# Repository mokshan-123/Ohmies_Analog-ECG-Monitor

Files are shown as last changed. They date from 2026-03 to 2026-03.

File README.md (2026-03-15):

#  Heart ECG Monitor — Ohmies

A portable, battery-powered analog front-end for single-lead ECG signal acquisition, designed as part of the **EN2091 Laboratory Practice and Projects Module** at the University of Moratuwa, Faculty of Engineering, Department of Electronic and Telecommunication Engineering.

---

##  Team — Ohmies | Contributors

| Name | Index |
|---|---|
| Keerawella K.P.C.P. | 230332B |
| Jathunwaththa J.C.R.N. | 230266B |
| Induwara M.L.A.S. | 230261F |
| Colombage D.M. | 230108U |

---

##  Repository Structure

```
Ohmies_ECG/
├── PCB_Files/           # EasyEDA Pro PCB design files
├── Schematic_Files/     # Circuit schematics
├── Enclosure_Files/     # SolidWorks & STL files for the 3D printed enclosure
├── Docs/                # Images, photos, and project documents
│   ├── block_diagram.png
│   ├── sch.png
│   ├── bode_plot.png
│   ├── transient_response.png
│   ├── enclosure_front.jpg
│   ├── enclosure_open.jpg
│   ├── Final_Report.pdf
│   ├── Presentation.pdf
│   ├── User_Manual.pdf
│   └── Datasheet.pdf
├── LICENSE
└── README.md
```

---

##  Overview

This project implements a complete analog signal conditioning chain to capture, amplify, and filter biopotential ECG signals from the human body. ECG signals are extremely low amplitude (microvolts to millivolts) and are typically corrupted by power-line interference, baseline wander, and muscle artifacts. The device addresses all of these challenges in hardware.

The system was designed with emphasis on **patient safety**, **signal integrity**, and **noise rejection**, and successfully acquired live ECG waveforms with clearly identifiable P, QRS, and T complexes.

---

##  Documents

| Document | Link |
|---|---|
| Final Report | [Final_Report.pdf](./Docs/Final_Report.pdf) |
| Presentation | [Presentation.pdf](./Docs/Presentation.pdf) |
| User Manual | [User_Manual.pdf](./Docs/User_Manual.pdf) |
| Datasheet | [Datasheet.pdf](./Docs/Datasheet.pdf) |

---

##  System Architecture

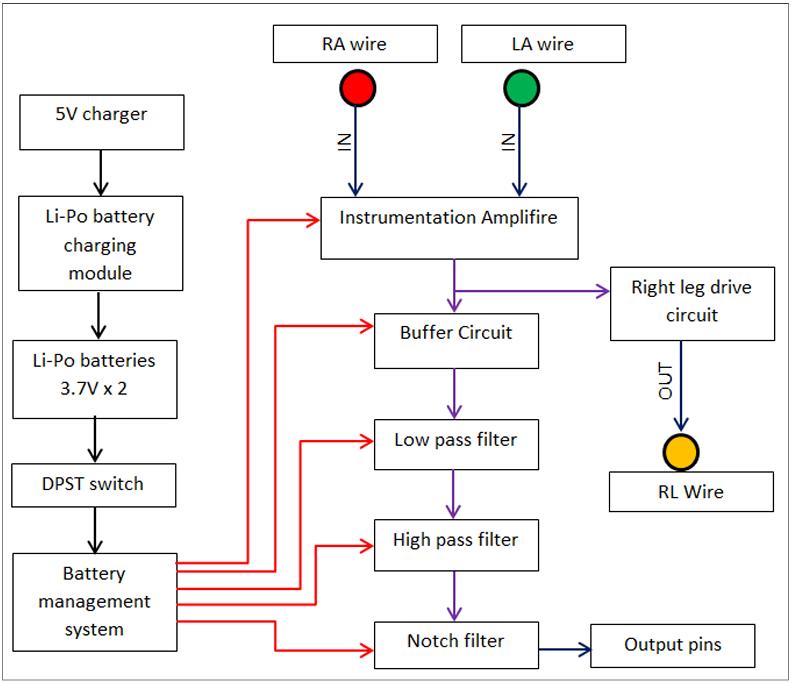
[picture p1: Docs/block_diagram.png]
Block Diagram


---

##  Circuit Stages

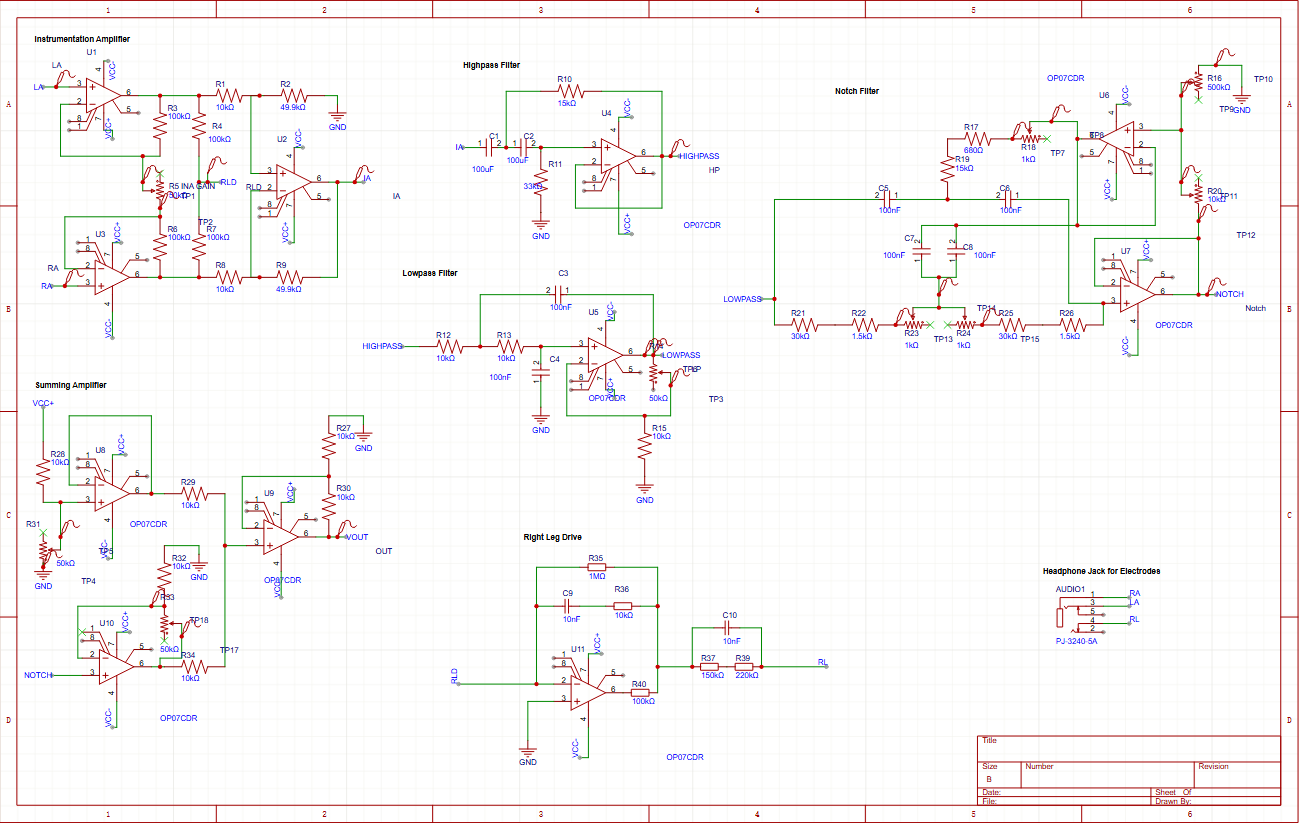
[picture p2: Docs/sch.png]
Schematic


### Instrumentation Amplifier
- Extracts the differential signal between the Left Arm (LA) and Right Arm (RA) electrodes
- High input impedance, high CMRR
- Adjustable gain via external resistor R5:

$$V_{IA} = \frac{R_2}{R_1}\left(1 + \frac{2R_3}{R_5}\right)(V_{LA} - V_{RA})$$

### Right Leg Drive (RLD)
- Actively cancels common-mode interference by sensing, inverting, and feeding it back to the body via the RL electrode
- Significantly improves effective CMRR and prevents static charge buildup

### High-Pass Filter
- Topology: 2nd-order Sallen–Key HPF
- Cutoff frequency: **~0.072 Hz**
- Components: R10 = 15 kΩ, R11 = 33 kΩ, C1 = C2 = 100 µF
- Removes DC offsets, baseline wander, and slow motion artifacts

### Low-Pass Filter
- Topology: 2nd-order adjustable-gain Sallen–Key LPF
- Cutoff frequency: **~159.2 Hz**
- Components: R12 = R13 = 10 kΩ, C3 = C4 = 100 nF
- Removes electromyographic interference and high-frequency EM noise

### Notch Filter
- Topology: Active twin-T notch filter with multiple feedback
- Notch frequency: **~50.37 Hz**
- Components: R = 31.6 kΩ, C = 100 nF
- Suppresses 50 Hz power-line interference

### Power Circuit
- Dual ±3.7 V supply from two series-connected Li-Po batteries
- Battery-powered for electrical isolation from mains and reduced 50 Hz susceptibility
- Includes a BMS (Battery Management System) and USB-C charging via a Li-Po charging module
- Controlled by a DPST switch

---

##  PCB Design

- **Tool:** EasyEDA Pro
- **Stackup:** 4-layer — Signal-1 / Power / GND / Signal-2
- Solid ground plane with ground fills on all layers, stitched via vias
- Wide power traces to minimise inductance and heating
- Analog signal paths kept short and isolated from power regulation circuitry

---

##  Enclosure

- **CAD Tool:** SolidWorks
- **Material:** PLA (3D printed)
- **Dimensions:** 110 mm × 80 mm × 60 mm
- **Features:**
  - Power switch
  - 3.5 mm audio jack for electrode input
  - USB-C charging port
  - Header pins for oscilloscope output
  - Ventilation openings
  - Internal compartment for batteries and BMS

>  SolidWorks and STL files are available in the [`Enclosure_Files/`](./Enclosure_Files) folder.

---

## 🔩 Final Prototype

| Front View | Internal Assembly |
|---|---|
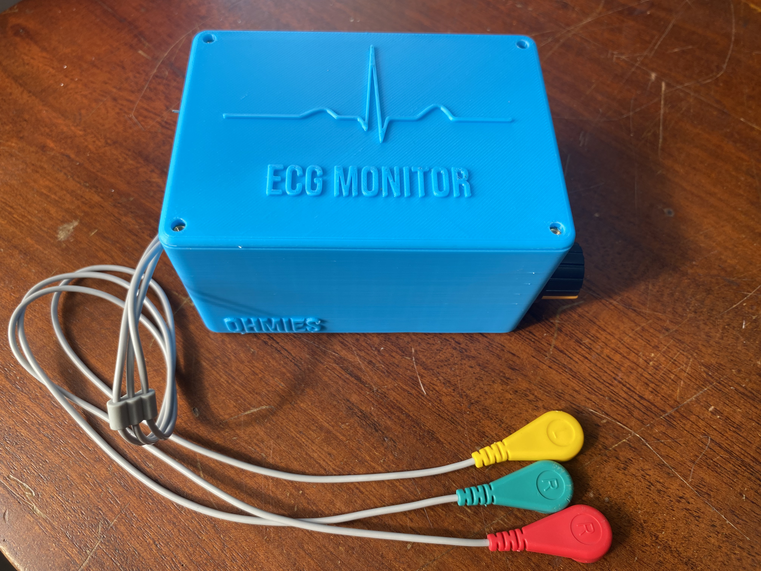
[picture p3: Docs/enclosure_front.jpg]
Enclosure Front
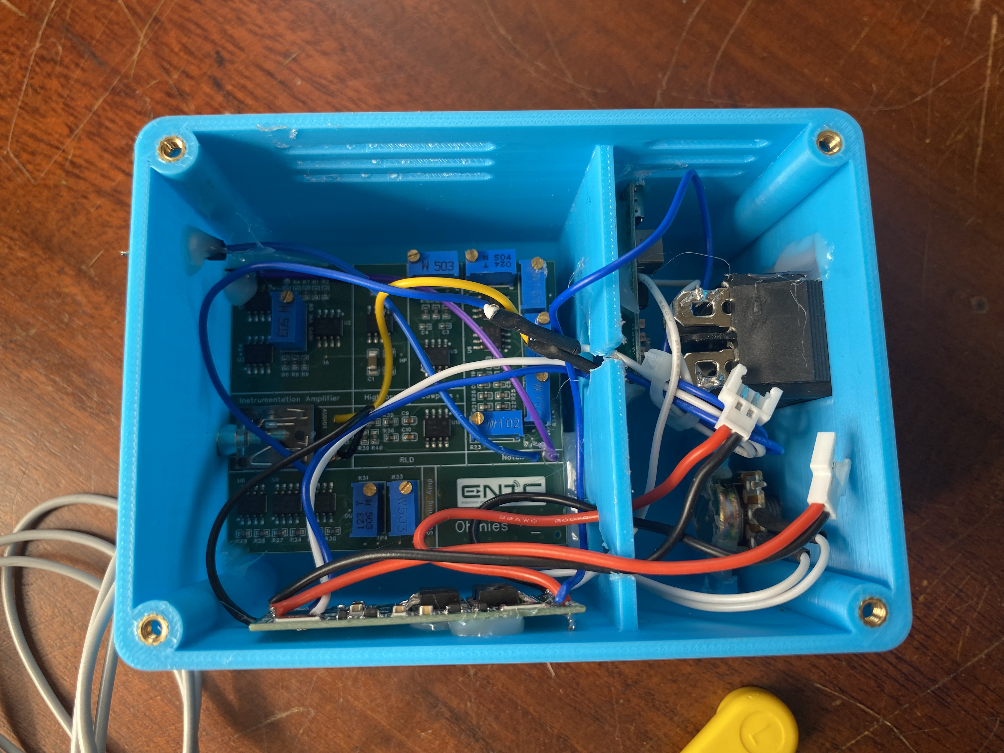
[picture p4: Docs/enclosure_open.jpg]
Enclosure Open
|  |  |

---

##  Testing & Results

### Simulation (LTSpice)
- Bode plot analysis confirmed correct passband and stopband behaviour across all filter stages
- Transient analysis verified effective 50 Hz attenuation while preserving ECG morphology

**Bode Plot — Combined filter frequency response:**

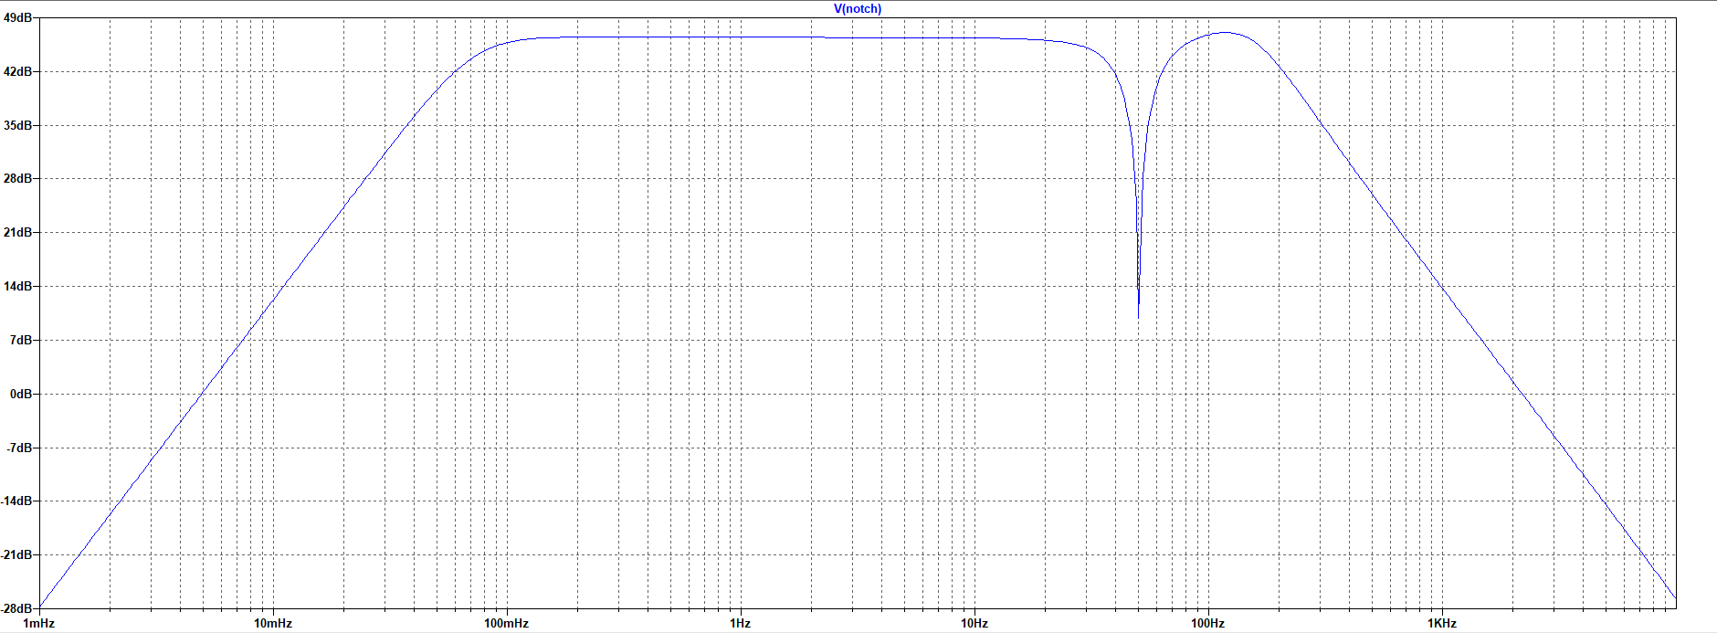
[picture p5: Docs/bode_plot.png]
Bode Plot


**Transient Response — Input (blue) vs. notch filter output (green):**

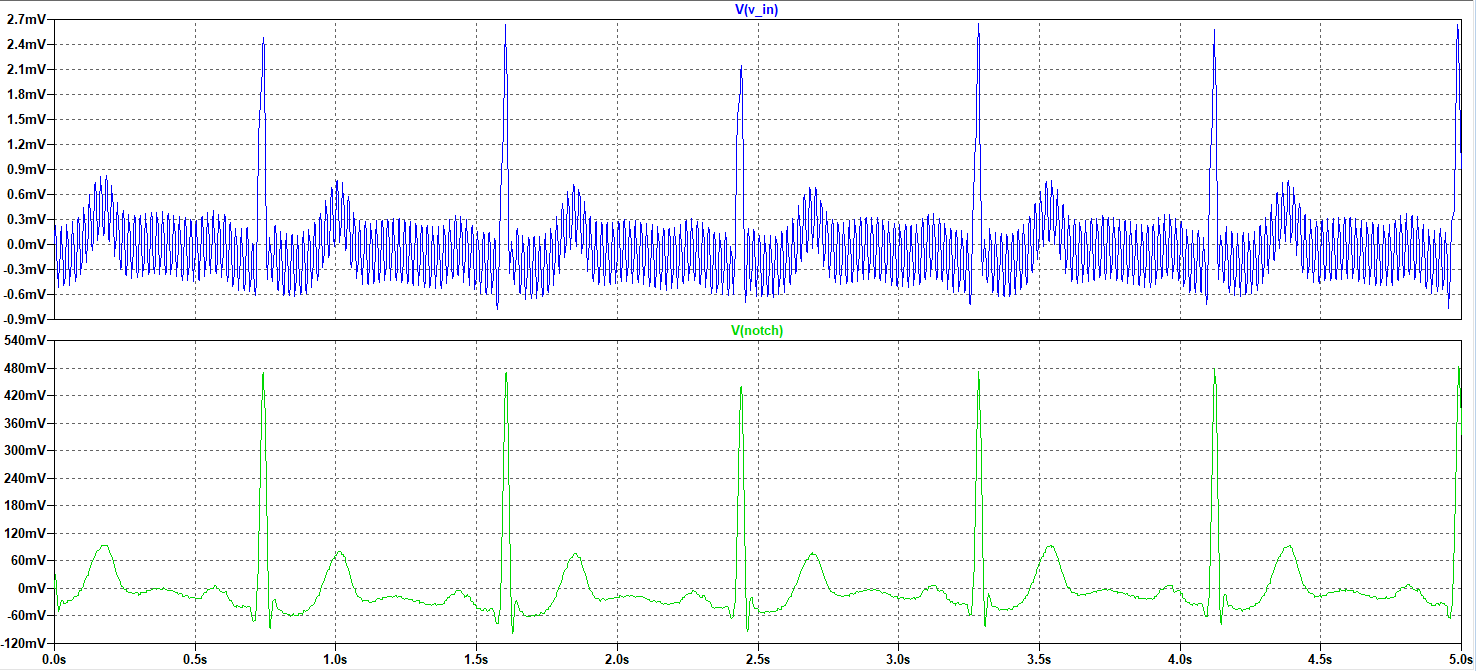
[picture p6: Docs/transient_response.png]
Transient Response


### Hardware Testing
1. **Breadboard prototype** — iterative tuning of gain and cutoff frequencies, cross-verified in LTSpice
2. **PCB prototype** — continuity checks, functional tests; results consistent with simulation
3. **Live subject test** — clearly identifiable P, QRS, and T complexes acquired via surface electrodes

---

##  Bill of Materials (Key Components)

| Component | Quantity |
|---|---|
| OP07 Op-Amp | 11 |
| 10 kΩ Resistor | 12 |
| 100 nF Capacitor | 6 |
| 100 µF Capacitor | 2 |
| 49.9 kΩ Resistor | 2 |
| 100 kΩ Resistor | 5 |
| 50 kΩ Trimmer | 4 |
| 1 kΩ Trimmer | 3 |
| Li-Po Battery (3.7 V) | 2 |
| Battery Management System | 1 |
| ECG wire set (3.5 mm jack) | 1 |

> See the full BOM in the [Final Report](./Docs/Final_Report.pdf).

---

##  Future Improvements

- Onboard OLED/TFT display for real-time waveform visualisation
- ESP32 integration for Wi-Fi/Bluetooth wireless monitoring
- Cloud-based ECG storage and remote access
- Real-time R-peak detection and BPM calculation
- Digital FIR/IIR filters to supplement or replace analog stages
- Adaptive filtering for motion artifact suppression
- SD card data logging and playback
- Multi-lead ECG expansion
- Low-power optimisation for extended battery life
- Enhanced isolation and medical device safety compliance

---

##  References

1. Webster, J. G. (2009). *Medical Instrumentation: Application and Design.* John Wiley & Sons.
2. Winter, B. B., & Webster, J. G. (1983). Driven-right-leg circuit design. *IEEE Transactions on Biomedical Engineering*, (1), 62–66.
3. Texas Instruments. (2019). *A Basic Guide to Thermocouple Measurements* (Application Note).

---

*University of Moratuwa — Faculty of Engineering — Department of Electronic and Telecommunication Engineering*

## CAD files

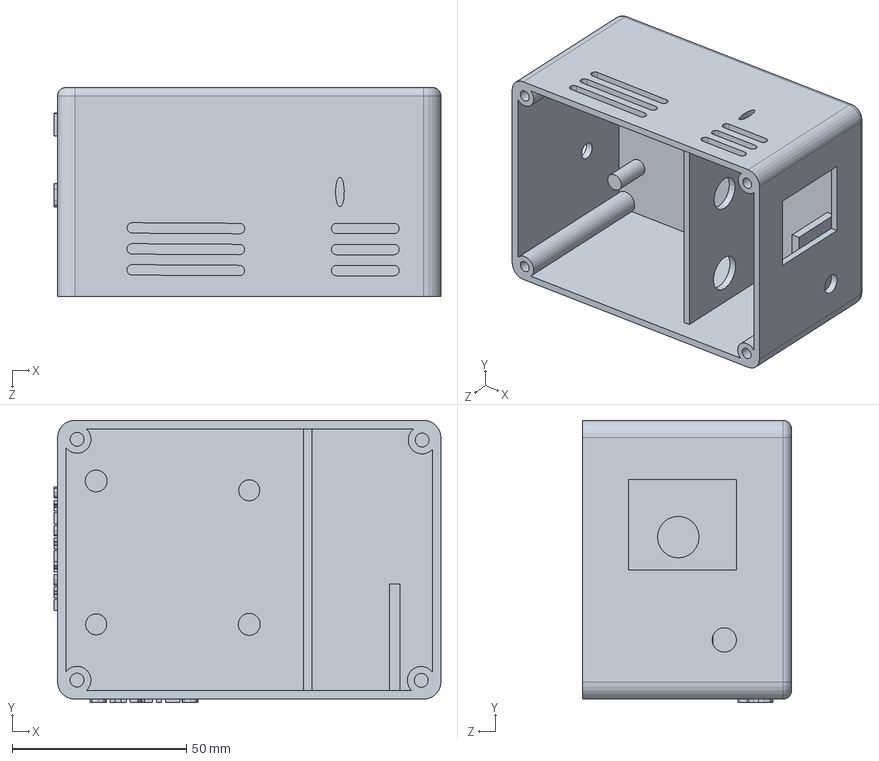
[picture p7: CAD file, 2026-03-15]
Enclosure_Files/Box.SLDPRT
111.0 x 81.0 x 60.0 mm

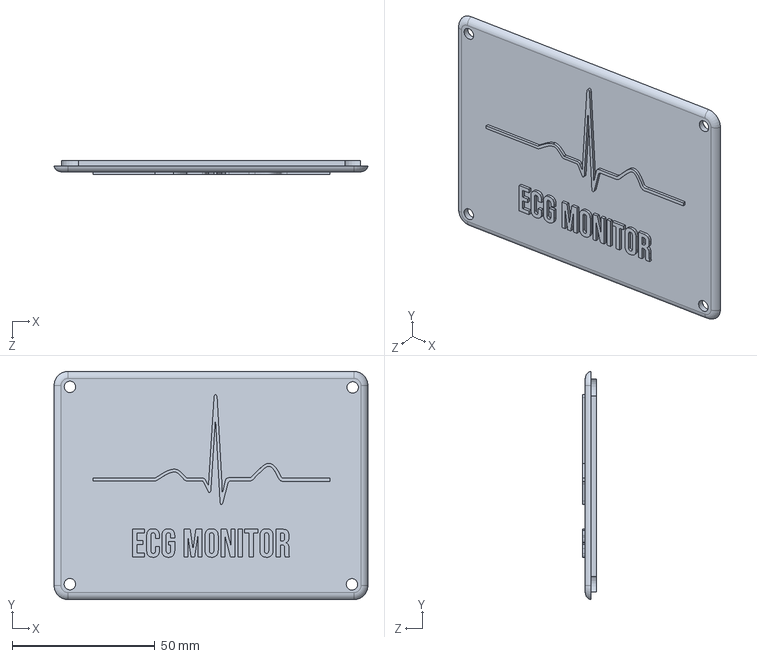
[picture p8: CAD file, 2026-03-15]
Enclosure_Files/Lid.SLDPRT
109.9 x 79.9 x 5.00 mm

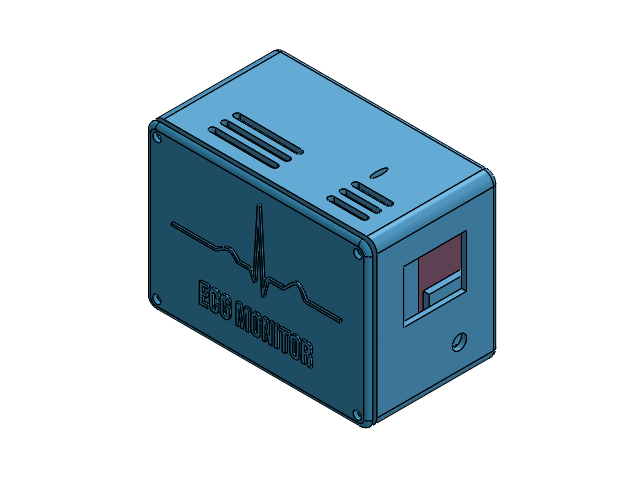
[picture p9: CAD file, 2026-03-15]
Enclosure_Files/Assembly.SLDASM
Lid.step
Box.step

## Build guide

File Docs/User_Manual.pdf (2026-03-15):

# Heart ECG Monitor

### by ohmies

# User Manual

## 1. Introduction

The Electrocardiogram (ECG) Machine is an electronic medical device designed to acquire, amplify, and display the electrical activity of the heart. By detecting the bioelectrical signals generated during each cardiac cycle, the device produces an ECG waveform that represents heart rhythm and electrical conduction.

This user manual provides comprehensive instructions for the installation, operation, and basic care of the ECG machine. It is intended to assist users in understanding the device functionality, ensuring correct usage, and maintaining reliable performance. The manual also outlines important safety information to help prevent improper operation and potential hazards.

The ECG machine enables monitoring of fundamental ECG features such as the P wave, QRS complex, and T wave, which are essential for observing cardiac activity. Proper adherence to the procedures described in this manual ensures accurate signal acquisition and stable operation of the device.

Users are advised to read this manual carefully before operating the ECG machine and to follow all instructions and warnings provided to ensure safe and effective use.

## 2. Package Contents

- ECG Monitor unit
- ECG input cable with 3 inputs (LA, RA, RL)
- 6 ECG electrodes
- Charging module
- User manual

## 3. Safety Information

To ensure safe operation and prevent potential hazards, carefully observe the following safety instructions when using the ECG monitor. Failure to follow these instructions may result in equipment damage, inaccurate readings, or personal injury.

### 0.1 General Safety Warnings

- This device is not intended for medical diagnosis, treatment, or clinical decisionmaking.
- The ECG monitor is designed for external, non-invasive signal acquisition only.
- Use the device strictly according to the instructions provided in this user manual.
- Do not modify the device circuitry, enclosure, or firmware. Unauthorized modifications may compromise safety and performance.

### 0.2 Electrical Safety

- The ECG monitor is powered exclusively by rechargeable Li-Po batteries.
- Do not connect the device to any external power source other than the specified charging method.
- Use only the recommended charger and charging circuitry.
- Do not operate the device while charging unless explicitly specified.
- Do not short-circuit, puncture, overheat, or disassemble the batteries.
- Stop using the device immediately if the battery shows signs of swelling, leakage, excessive heating, or odor.
- Recharge batteries only within the specified voltage and current limits.

### 0.3 Patient Safety

- Do not use the device on individuals with implanted electronic devices, such as pacemakers or implantable cardioverter-defibrillators (ICDs).
- Use only insulated, skin-safe ECG electrodes intended for bio-signal acquisition.
- Ensure correct electrode placement before starting the measurement.
- Do not place electrodes on broken, irritated, or infected skin.
- Discontinue use immediately if the subject experiences discomfort, pain, or skin irritation.

### 0.4 Environmental Conditions

- Keep the device away from moisture, water, and liquids.
- Do not operate the ECG monitor in wet, humid, or explosive environments.
- Avoid exposure to extreme temperatures, direct sunlight, or excessive dust.
- Operate the device only within the specified environmental conditions.

### 0.5 Handling and Maintenance

- Handle the ECG monitor with care to prevent mechanical damage.
- Do not drop, crush, or apply excessive force to the device or electrodes.
- Clean the enclosure using a soft, dry cloth. Do not use solvents or abrasive cleaning agents.
- Disconnect electrodes from the subject before cleaning or storing the device.

### 0.6 Electromagnetic Interference

- Keep the ECG monitor away from strong electromagnetic sources such as mobile phones, power inverters, motors, and RF transmitters.
- Electromagnetic interference may cause waveform distortion or unstable readings.

### 0.7 Disposal

- Store the device in a clean, dry location when not in use.
- Dispose of the device, batteries, and accessories in accordance with local regulations for electronic and battery waste.
- Do not dispose of batteries in fire or household waste.

## 4. Device Overview

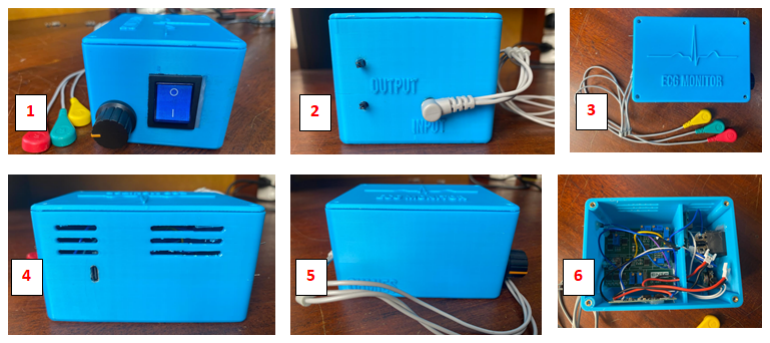
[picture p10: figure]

Figure 1 : Power switch and Amplitude controller Figure 2 : Input port and output pins
Figure 3 : Top View
Figure 4 : Rear View
Figure 5 : Front View
Figure 6 : Inside View with circuit and battery compartment

## 5. Controls and Indicators

- Power Input: 5V DC (charging)
- Battery Voltage: 3.7v Li-Po battery x 2
- Electrode Ports: LA, RA, RL
- Analog Output: ECG waveform output

## 6. How to Connect the Electrodes

1. Ensure the device is powered OFF before connecting the electrodes.
2. Clean the electrode placement areas with alcohol and allow the skin to dry completely.
3. Attach the RA (Red) (Right Arm) electrode to the right arm or right shoulder area.
4. Attach the LA (Green) (Left Arm) electrode to the left arm or left shoulder area.
5. Attach the RL (yellow) (Right Leg / Reference) electrode to the lower abdomen or waist area.
6. Verify that all electrodes are firmly attached to the skin.
7. Connect the electrode lead wires securely to their corresponding connectors on the device.
8. connect the output pins to the display through cables
9. Power ON the device and confirm that a stable ECG waveform is displayed and tune the waveform if the signal is unclear by using the Amplitude controller.

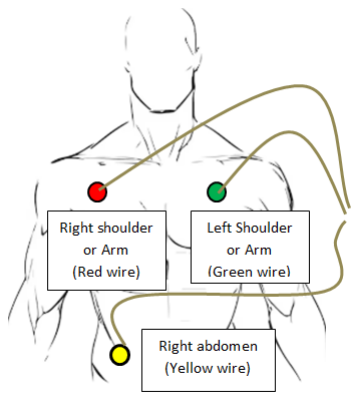
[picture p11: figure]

figure : ECG electrode connection Note

- Ensure good skin contact to reduce motion artifacts and noise.
- Avoid placing electrodes over bone, muscle tension areas, or excessive hair.
- Reposition electrodes if the signal appears unstable or noisy.

Caution

- Do not attach electrodes to broken or irritated skin.
- Disconnect electrodes immediately after use.

## 7. Operating Instructions

Follow the steps below to operate the ECG monitor correctly.

1. Ensure the device batteries are sufficiently charged.
2. Confirm that the electrodes are connected to the subject as described in Section 6.
3. Connect the ECG output to the monitoring interface (oscilloscope or ADC input), if applicable.
4. Power ON the device using the power switch.
5. Allow a few seconds for the signal to stabilize.
6. Observe the ECG waveform, including the P wave, QRS complex, and T wave
7. Tune the output waveform by adjusting the amplitude controller.
8. Minimize subject movement during measurement to reduce motion artifacts.
9. After use, power OFF the device and disconnect the electrodes from the subject.

Note

- Initial signal instability may occur during startup.
- Proper grounding and reference electrode placement improve signal quality.

## 8. Expected Output

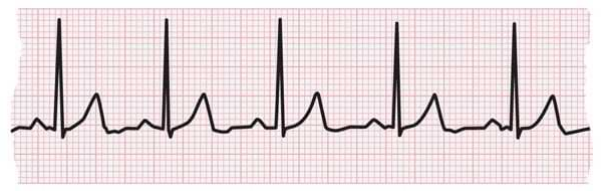
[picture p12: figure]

## 9.Troubleshooting

This section provides guidance for identifying and resolving common issues that may occur during operation of the ECG monitor.

### 9.1 No Output / Flat Signal

- Verify that all electrodes are properly attached to the subject with good skin contact.
- Ensure adequate electrode gel is used and the skin is clean and dry.
- Confirm that the ECG monitor is powered ON.
- Check that both rechargeable Li-Po batteries are sufficiently charged.
- Inspect electrode cables and connectors for loose connections or damage.
- Ensure correct electrode placement according to the specified lead configuration.

### 9.2 Excessive Noise or Unstable Baseline

- Ensure electrode wires are not moving during measurement.
- Keep ECG cables away from mains power cables, transformers, and switching power supplies.
- Avoid operating the device near strong electromagnetic interference sources.
- Ensure the subject remains relaxed and minimizes body movement.
- Verify proper contact of the reference (ground) electrode.

### 9.3 Distorted or Attenuated R-Peaks

- Adjust the gain control potentiometer to an appropriate level.
- Verify correct operation of the amplifier gain stages.
- Ensure input filtering stages (high-pass and low-pass filters) are functioning correctly.
- Check for incorrect electrode placement or poor electrode contact.
- Avoid excessive gain settings that may cause amplifier saturation.

### 9.4 Signal Saturation or Clipping

- Reduce the gain using the gain control potentiometer.
- Ensure the ECG signal amplitude is within the designed input range.
- Check battery voltage levels, as low supply voltage may reduce amplifier headroom.
- Inspect the analog front-end for DC offset or drift.

### 9.5 Baseline Drift

- Allow the device to stabilize for a few seconds after power-on.
- Ensure stable electrode contact and minimal subject movement.
- Verify proper operation of the baseline stabilization (high-pass filtering) circuit.
- Avoid sudden posture changes during measurement.

### 9.6 Intermittent Signal Loss

- Check for loose or intermittent electrode lead connections.
- Inspect battery terminals and internal power connections.
- Ensure the rechargeable batteries are not deeply discharged.
- Verify that the gain control potentiometer is not at an unstable or extreme position.

### 9.7 Low Signal Amplitude

- Gradually increase the gain using the gain control potentiometer.
- Confirm correct electrode placement.
- Ensure electrode gel has not dried out.
- Verify that the batteries are fully charged.

### 9.8 Device Does Not Power On

- Recharge the Li-Po batteries using the specified charging method.
- Verify correct battery polarity and secure connections.
- Check the power switch for proper operation.
- Inspect the power circuitry for visible damage.

### 9.9 Charging Issues

- Use only the recommended charging voltage and current.
- Inspect the charging cable and connector for damage.
- Do not operate the device if batteries show signs of swelling or overheating.
- Allow sufficient charging time before use.

## 10.Maintenance

Proper maintenance of the ECG monitor ensures reliable operation, measurement accuracy, and extended device lifespan.

### 10.1 Storage

- Store the ECG monitor in a clean and dry environment.
- Avoid exposure to excessive humidity, dust, or direct sunlight.
- Store the device within the specified temperature range.

### 10.2 Cleaning

- Clean the electrodes after every use to prevent contamination.
- Use a soft cloth lightly moistened with a mild disinfectant or alcohol solution.
- Ensure electrodes are completely dry before the next use.
- Do not immerse the device or electrodes in water or cleaning liquids.

### 10.3 Battery Maintenance

- Recharge the Li-Po batteries using the recommended charging method.
- Avoid deep discharge of the batteries to prolong battery life.
- Do not use the device if the batteries show signs of swelling, leakage, or overheating.

### 10.4 General Precautions

- Do not attempt to disassemble the device.
- Inspect cables and connectors periodically for damage.
- If abnormal operation is observed, discontinue use and inspect the device.

## 11. Warranty

This ECG monitor is provided as part of an academic and experimental project. The device is intended for educational and laboratory use only.

The manufacturer provides a limited warranty covering manufacturing defects in materials and workmanship for a period of six (6) months from the date of assembly or first use.

This warranty does not cover:

- Damage caused by improper use, misuse, or unauthorized modification.
- Damage resulting from incorrect power supply, charging methods, or battery mishandling.
- Normal wear and tear of electrodes, cables, and connectors.
- Damage caused by exposure to moisture, liquids, or extreme environmental conditions.

The warranty is void if the device is disassembled or modified without authorization. The manufacturer shall not be held responsible for any indirect, incidental, or consequential damages arising from the use of this device.

Note: This device is not certified for clinical or medical diagnostic use.
